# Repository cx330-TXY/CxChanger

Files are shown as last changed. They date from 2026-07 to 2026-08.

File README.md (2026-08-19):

# [CxChanger]

[CxChanger]是一种FDM3D打印多材料/多色解决方案。通过在打印打印过程中切换预热好的装载不同耗材的热端实现快速多材料打印。其目标是实现尽可能低成本且简单稳定的多材料打印，为了实现较高的适配性，热端切换只需要打印头XY轴运动就可实现，且切换结构与热端无关，可以通过修改热端固定件等实现其他热端的兼容。

English language readme is available [here](./EN-translation/README-EN.md)

打印头

QQ20260404-193802

---

## 核心特性
- **自动预热**：开启orcaslicer中的Ooze预防功能，会根据自己设定的预热时间提前在切换材料前插入预热命令，切换时释放旧热端并切换到待机温度然后抓取已经预热好的热端，若下一次切换的时间短于加热时间则保持温度不降温。
- **欠驱动切换机构**：采用欠驱动设计不需要额外增加主动元件，利用打印头自身的XY轴运动与停靠坞机械交互来实现热端切换和耗材丝夹紧松开。
- **磁吸麦克斯韦定位耦合机构**：热端模块锁定采用N52磁铁磁吸配合[麦克斯韦耦合](https://en.wikipedia.org/wiki/Kinematic_coupling)定位机构，打印头端有定位销组成的三个槽口，热端模块端有圆头销头部组成的球头。磁吸配合时实现对热端模块空间六自由度的限位，不存在过定位所以即使有加工装配误差以及磨损变形热端模块都能自适应消隙精确定位。
- **自动喷嘴偏移量校准**:采用校准器校准每个头XYZ轴相对T0的偏移量，可以使用如[小球微动接触式喷嘴偏移量校准](https://github.com/Noisyfox/FoxChanger/tree/main/NozzleProbe)或者[无接触涡流喷嘴偏移量校准](https://oshwhub.com/cxg01/project_lbabffjk)，接触式需要清理干净喷嘴才能获得正确喷嘴偏移量，无接触可以不清理喷嘴。不需要每次打印前都校准，通常在刚装配好或者出现撞头等情况需要校准。

## 硬件与软件需求

### 硬件
* **打印机** 原理上支持打印头具有XY移动能力的机型（如voron2.4、voron三叉戟、大鱼TT等），本开源只提供打印头和基础停靠坞设计需要根据自己机型固定装载停靠坞的铝型材和其他兼容修改。
* **主板** 由于采用有线加热，每个热端模块具有一个加热片和热敏，可利用主板空余接口来扩展少量热端模块，若需要扩展更多热端模块需要制作[扩展板]( https://oshwhub.com/rayzark/project_qxihkkhj)来增加主板的加热棒接口和热敏接口。

### 软件
* **固件** 整体热端切换通过klipper宏命令实现，若需使用喷嘴偏移量校准则需要下载[toolchange](https://github.com/viesturz/klipper-toolchanger)插件，配合自动校准宏来实现。
* **切片软件**：采用Orcaslicer，其他切片软件可自行探索。

## 组成概览

### 组成部分
- 打印头：有除了热端以外的其他部分
- 热端模块：包含热端，接有铁氟龙管和加热片和热敏的线
- 停靠坞：用于存放停靠的热端，可以堵住停靠热端的嘴防止漏料，以及有散热风扇给停靠的热端进行散热（无封箱的采用侧面离心风扇对所有热端进行散热、有封箱的采用每个停靠坞一个轴流风扇）。

### 零件
#### 打印版
- 1.5×5（直径*长）圆柱销：用于构成麦克斯韦耦合定位的槽（×6）
- 3×6（直径*长）圆头销：用于构成麦克斯韦耦合定位的球（一个热端3个）
- 5×20（直径*长）内螺纹圆头销：装配于停靠坞上用于撑开挤出机摆臂（一个停靠坞1个）
- 6×4（直径*厚）N52磁铁：用于吸附热端模块到打印头上和停靠坞上（一个热端3个，一个停靠坞1个，打印头3个）
- M3×6沉头螺丝
- M3×25螺丝
- M3×8螺丝
- M3×10螺丝
- M3×12螺丝
- M3×14螺丝
- M3×20螺丝
- M2.5×16螺丝
- M2×8螺丝
- M3×4×4热熔螺母
- HGX挤出机齿轮组
- 4020蜗轮风扇
- 2510轴流风扇
- 欧姆龙微动开关
- 10×2（宽×厚）自粘耐热硅胶条
#### CNC版
见bom表

## 安装与配置指南

### printer.cfg
   Printer.cfg主体可以沿用自己以前的，参考我的printer.cfg里的格式和下面的提示修改，也可以直接用我的然后改成自己主板的引脚。
   1. 引用 toolchange.cfg 和 calibration.cfg。
   2. 仿照extruder1格式定义增加的热端，加热棒热敏引脚按自己主板接线来，共用E0的挤出机，其他的为虚拟挤出机。
   3. probe采用固定微动，开始打印时热端全部停放于停靠坞中用耐高温硅胶垫堵嘴，加热到目标温度才拿出来解决初始漏料问题，不需要擦嘴，调平时未抓取热端此时微动为打印头最低点。还未支持其他调平方式，建议直接参考我的probe相关配置包括网床和调平的配置（主要是增加了调平前释放抓取的热端）。
   4. 添加停靠坞散热风扇配置，停靠坞散热风扇和喉管冷却风扇关联的挤出机里添加所有挤出机。
   5. 修改打印开始gcode，实现打印前自动给要使用的热端进行挤出划线。
   6. 修改打印结束gcode，添加UNTOOL命令保证打印完自动卸载热端，让下次打印时不用自己手动取下热端。增加关闭所有热端加热命令。
### toolchange.cfg
   1. 添加toolchange.cfg。添加成功后仪表盘界面会出现T0、T1、T2以及、UNTOOL命令，（没调坐标先别点、会直接撞）点击T0是抓去T0，抓取T0后再点击T1坐标会自动卸载T0然后抓取T1，点击UNTOOL是卸载当前热端。
   2. 固定停靠坞以及调整停靠坞坐标：手动把热端装到打印头上，把打印头拖动到X轴最右边，再往前拖动，然后把第一个停靠坞固定在能刚好让热端锁定螺丝穿过停靠坞大孔的位置（这个位置即为第一个停靠坞的坐标），然后取下热端，点击全部归位，再把热端装到打印头上，慢慢移动打印头到刚才找到的停靠坞位置让锁定螺丝穿过停靠坞大孔，记下此时的坐标将其填入toolchange里T0的停靠坞位置，一个停靠坞占30mm宽度，其他停靠坞坐标用等差数列得到，如有误差可自己微调每一个停靠坞的坐标。 
   

   3. 正确设置坐标后，注释正常速度，解除测试速度注释，用慢速进行切换测试，（方便看到没对齐直接点急停）。
   4. 测试速度切换正常后，注释测试速度，解除正常速度注释（可以根据自己机器情况自己测试出更为合适的速度）。
### calibration.cfg
   1. 下载[toolchange](https://github.com/viesturz/klipper-toolchanger)插件
   1. 添加calibration.cfg
   2. 归位xyz，调平完成后，固定好校准器，点击T0抓去第一个热端，移动至喷嘴尖端刚好位于校准器中心正上方距离1mm左右，记下这个时候的坐标，填入calibration.cfg里校准器坐标处，然后还需要在里面自己定义一个停靠坞范围外的安全位置，防止校准的时候撞到停靠坞里的其他热端。
   3. 坐标设置好后输入 CALIBRATE_TOOL TOOL=_ 可以校准指定热端（需要先校准T0），输入 CALIBRATE_ALL_TOOLS 可以校准全部（需要设定好有哪些热端），校准完成会自动存储偏移量。
### orcaslicer
   1. 修改打印机gcode里起始和耗材丝更换gcode、设置更多挤出机(根据自己热端数填写)、设置各挤出机切换耗材时回抽量（我设置的长度2mm）。
- 打印起始Gcode(根据自己的热端数修改)：
```Gcode
PRINT_START BED=[first_layer_bed_temperature] INITIAL_TOOL=[initial_tool] T0_TEMP={nozzle_temperature_initial_layer[0]} T0_USED={is_extruder_used[0]} T1_TEMP={nozzle_temperature_initial_layer[1]} T1_USED={is_extruder_used[1]} T2_TEMP={nozzle_temperature_initial_layer[2]} T2_USED={is_extruder_used[2]} T3_TEMP={nozzle_temperature_initial_layer[3]} T3_USED={is_extruder_used[3]} T4_TEMP={nozzle_temperature_initial_layer[4]} T4_USED={is_extruder_used[4]}
```
- 耗材更换Gcode：
```Gcode
M104 S{nozzle_temperature[next_extruder]} T{next_extruder}
T{next_extruder}
```
   2. 工艺栏里开启擦拭塔（如果料和参数调得好，且模型不涉及快速微小挤出，可以把模型拖到停靠坞旁边关掉擦料塔尝试无擦料塔打印）和Ooze自动预热（我设置的软化温度负180，预热时间35s，根据自己热端加热速度修改）。

## 注意事项
- 打印件采用abs打印，4层墙，60%填充。
- 挤出机弹簧需要拧得比常规挤出机更紧（因为为了压缩空间，力臂长度有限相同预紧力下挤出机夹紧力不如正常挤出机）。
- 为了减少热量传导效率，用到的TZ2.0热端需要去掉固定加热块的两个螺丝，仅靠侧面顶丝固定。
- 磁铁安装严格按图来（有的是压到底，有的是与某一面共面），装配正确应该是只有热端组件端的圆头销与背板端的圆柱销槽接触，磁铁之间有一点间隙，才能实现麦克斯韦耦合定位的自动消隙功能，可以自己晃动热端感觉有没有虚位，有虚位需要检查安装是否正确。当出现打印着精度变差的情况，需检查定位装配，容易出现磁铁没粘牢滑出与另一端的磁铁接触造成麦克斯韦耦合失效。
- 热端组件上用来挂在停靠坞孔里的挂钩螺丝用12.9级的杯头螺丝方便磁吸到停靠坞内，304材质螺丝无法正常吸附。

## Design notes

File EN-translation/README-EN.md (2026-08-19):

# [CxChanger]

> **Attribution / Credit**: Initial translation courtesy of [WheelsTheCat](https://github.com/WheelsTheCat/CxChanger). Translated content includes the README, Klipper configuration comments/messages, BOM spreadsheet, file names. For a translated STEP file refer to his repository.

[CxChanger] is a multi-material / multi-color solution for FDM 3D printing. It achieves fast multi-material printing by switching between preheated hotends loaded with different filaments during the print. The goal is multi-material printing that is as low-cost, simple, and stable as possible. For high adaptability, hotend switching only requires XY-axis motion of the print head, and the switching mechanism is independent of the hotend itself — other hotends can be made compatible by modifying the hotend mounting parts.
Print head

QQ20260404-193802

---

## Core Features
- **Automatic preheating**: With the Ooze Prevention feature enabled in OrcaSlicer, preheat commands are inserted before each material change according to your configured preheat time. During a switch, the old hotend is released and set to standby temperature, and the already-preheated hotend is picked up. If the time until the next switch is shorter than the heating time, the temperature is held without cooling down.
- **Underactuated switching mechanism**: The underactuated design requires no additional active components. It uses the print head's own XY-axis motion interacting mechanically with the dock to perform hotend switching and filament clamping/releasing.
- **Magnetic Maxwell kinematic coupling**: The hotend module is locked using N52 magnets combined with a [Maxwell coupling](https://en.wikipedia.org/wiki/Kinematic_coupling) locating mechanism. The print head side has three grooves formed by locating pins, and the hotend module side has ball ends formed by round-head pin tips. When magnetically coupled, all six spatial degrees of freedom of the hotend module are constrained. Because there is no over-constraint, the hotend module can self-adaptively compensate for backlash and locate precisely even with machining/assembly errors, wear, and deformation.
- **Automatic nozzle offset calibration**: A calibrator measures each head's XYZ offset relative to T0. You can use, for example, [ball-probe contact nozzle offset calibration](https://github.com/Noisyfox/FoxChanger/tree/main/NozzleProbe) or [non-contact eddy-current nozzle offset calibration](https://oshwhub.com/cxg01/project_lbabffjk). Contact calibration requires a clean nozzle for correct offsets; non-contact does not. Calibration is not needed before every print — it is typically only required after initial assembly or after events such as a head crash.

## Hardware and Software Requirements

### Hardware
* **Printer**: In principle, any machine whose print head can move in XY is supported (e.g., Voron 2.4, Voron Trident, BIQU/BigTreeTech, etc.). This open-source project only provides the print head and basic dock designs; you will need to adapt the aluminum extrusion mounting for the dock and make other compatibility modifications for your machine.
* **Main board**: Since wired heating is used, each hotend module has its own heater and thermistor. Spare ports on the main board can be used to add a small number of hotend modules. To add more, build an [expansion board](https://oshwhub.com/rayzark/project_qxihkkhj) to increase the number of heater and thermistor ports.

### Software
* **Firmware**: Hotend switching is implemented entirely through Klipper macros. If you want to use nozzle offset calibration, install the [toolchanger](https://github.com/viesturz/klipper-toolchanger) plugin and use it together with the automatic calibration macros.
* **Slicer**: OrcaSlicer is used; other slicers can be explored on your own.

## System Overview

### Components
- Print head: everything except the hotend
- Hotend module: contains the hotend, with PTFE tube and heater/thermistor wiring attached
- Dock: stores parked hotends. It plugs the nozzle of a parked hotend to prevent oozing, and has cooling fans for the parked hotends (open-frame machines use a side centrifugal fan cooling all hotends; enclosed machines use one axial fan per dock).

### Parts
#### Printed version
- 1.5×5 (diameter×length) cylindrical pins: form the grooves of the Maxwell coupling (×6)
- 3×6 (diameter×length) round-head pins: form the balls of the Maxwell coupling (3 per hotend)
- 5×20 (diameter×length) internally threaded round-head pin: mounted on the dock to spread open the extruder swing arm (1 per dock)
- 6×4 (diameter×thickness) N52 magnets: attach the hotend module to the print head and dock (3 per hotend, 1 per dock, 3 on the print head)
- M3×6 countersunk screws
- M3×25 screws
- M3×8 screws
- M3×10 screws
- M3×12 screws
- M3×14 screws
- M3×20 screws
- M2.5×16 screws
- M2×8 screws
- M3×4×4 heat-set inserts
- HGX extruder gear set
- 4020 blower fan
- 2510 axial fan
- Omron micro switch
- 10×2 (width×thickness) self-adhesive heat-resistant silicone strip
#### CNC version
See the BOM sheet

## Installation and Configuration Guide

### printer.cfg
   You can keep using your existing printer.cfg as the base. Modify it following the format in my printer.cfg and the notes below, or use mine directly and change the pins to match your board.
   1. Include toolchange.cfg and calibration.cfg.
   2. Define the additional hotends following the extruder1 format. Wire the heater and thermistor pins according to your board. They share E0's extruder motor; the others are virtual extruders.
   3. The probe uses a fixed micro switch. At print start, all hotends are parked in the dock with their nozzles plugged by the high-temperature silicone pads, and are only picked up once heated to the target temperature — this solves the initial oozing problem, and no nozzle wiping is needed. During leveling no hotend is attached, so the micro switch is the lowest point of the print head. Other leveling methods are not yet supported; it is recommended to use my probe-related configuration directly, including the bed mesh and leveling configuration (mainly the addition of releasing the grabbed hotend before leveling).
   4. Add the dock cooling fan configuration, and add all extruders to the extruder association of the dock cooling fan and the heatbreak cooling fan.
   5. Modify the print start G-code to automatically prime (extrude a line with) each hotend that will be used before printing.
   6. Modify the print end G-code to add the UNTOOL command so the hotend is automatically unloaded after printing, avoiding manual removal before the next print. Add commands to turn off all hotend heaters.
### toolchange.cfg
   1. Add toolchange.cfg. Once added successfully, T0, T1, T2 and UNTOOL commands will appear in the dashboard. (Do not click them before setting the coordinates — it will crash the head.) Clicking T0 picks up T0; after picking up T0, clicking T1 automatically unloads T0 and picks up T1; clicking UNTOOL unloads the current hotend.
   2. Mount the dock and adjust the dock coordinates: manually attach a hotend to the print head, move the print head to the far right of the X axis, then move it forward. Fix the first dock in the position where the hotend locking screw just passes through the dock's large hole (this position is the coordinate of the first dock). Then remove the hotend, home all axes, re-attach the hotend to the print head, and slowly move the print head to the dock position you just found so the locking screw passes through the dock's large hole. Note the coordinates and enter them as T0's dock position in toolchange.cfg. Each dock occupies 30 mm of width, so the other dock coordinates form an arithmetic sequence; fine-tune each dock's coordinates if there is any error.
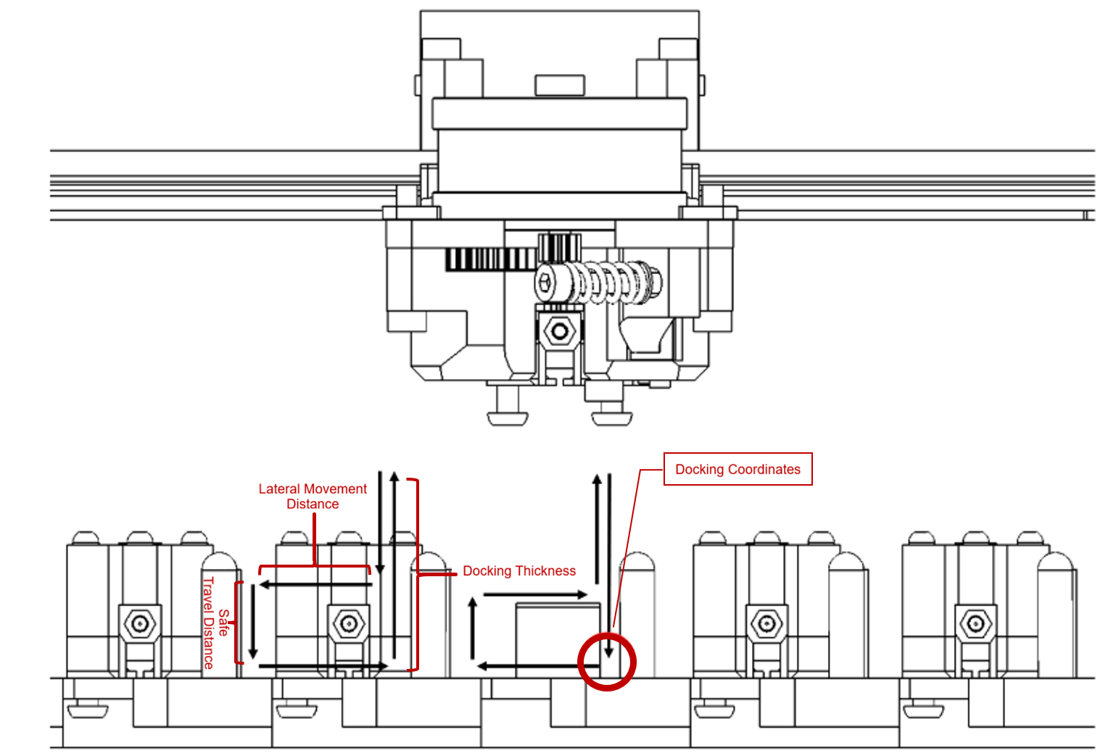
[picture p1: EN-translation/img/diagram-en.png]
Dock coordinate diagram
   

   3. After setting the coordinates correctly, comment out the normal speed and uncomment the test speed, then run switching tests at slow speed (so you can hit emergency stop immediately if anything is misaligned).
   4. Once switching works at test speed, comment out the test speed and uncomment the normal speed (you can test and tune more suitable speeds for your own machine).
### calibration.cfg
   1. Download the [toolchanger](https://github.com/viesturz/klipper-toolchanger) plugin
   1. Add calibration.cfg
   2. Home XYZ. After leveling completes, mount the calibrator, click T0 to pick up the first hotend, and move it until the nozzle tip is directly above the center of the calibrator at a distance of about 1 mm. Note the coordinates and enter them as the calibrator coordinates in calibration.cfg. You also need to define a safe position outside the dock area in the file, to avoid hitting the other hotends in the dock during calibration.
   3. Once the coordinates are set, run CALIBRATE_TOOL TOOL=_ to calibrate a specific hotend (T0 must be calibrated first), or CALIBRATE_ALL_TOOLS to calibrate all of them (set which hotends exist first). Offsets are stored automatically when calibration completes.
### orcaslicer
   1. In the printer G-code, modify the start G-code and the filament change G-code; configure additional extruders (according to your number of hotends); set the retraction amount for each extruder when switching filament (I use 2 mm).
- Print start G-code (modify according to your number of hotends):
```Gcode
PRINT_START BED=[first_layer_bed_temperature] INITIAL_TOOL=[initial_tool] T0_TEMP={nozzle_temperature_initial_layer[0]} T0_USED={is_extruder_used[0]} T1_TEMP={nozzle_temperature_initial_layer[1]} T1_USED={is_extruder_used[1]} T2_TEMP={nozzle_temperature_initial_layer[2]} T2_USED={is_extruder_used[2]} T3_TEMP={nozzle_temperature_initial_layer[3]} T3_USED={is_extruder_used[3]} T4_TEMP={nozzle_temperature_initial_layer[4]} T4_USED={is_extruder_used[4]}
```
- Filament change G-code:
```Gcode
M104 S{nozzle_temperature[next_extruder]} T{next_extruder}
T{next_extruder}
```
   2. In the Process settings, enable the wipe tower (if your filament and settings are well tuned and the model does not involve fast tiny extrusions, you can move the model next to the dock, disable the wipe tower, and try printing without one) and enable Ooze automatic preheating (I use a softening temperature offset of -180 and a preheat time of 35 s; adjust for your hotend's heating speed).

## Notes
- Printed parts should be printed in ABS with 4 walls and 60% infill.
- The extruder spring must be tightened more than on a regular extruder (to save space the lever arm is limited, so at the same preload the clamping force is lower than a normal extruder).
- To reduce heat conduction, the TZ2.0 hotend used here needs the two screws that fix the heater block removed, holding it only with the side set screw.
- Install the magnets exactly as shown in the drawings (some are pressed fully in, some are flush with a face). When assembled correctly, only the round-head pins on the hotend module side touch the cylindrical-pin grooves on the back plate side, with a small gap between the magnets — this enables the automatic backlash compensation of the Maxwell coupling. Wiggle the hotend to check for play; if there is play, check the installation. If print accuracy degrades during printing, check the locating assembly — a common issue is a magnet coming loose, sliding out, and contacting the magnet on the other side, which defeats the Maxwell coupling.
- The hook screws on the hotend module that hang in the dock holes should be grade 12.9 cap-head screws so they are attracted by the magnets in the dock; 304 stainless steel screws will not be attracted properly.

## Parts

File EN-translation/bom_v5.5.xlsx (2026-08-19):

Item No. | Part No. | Quantity | Price | Link
HGX extruder gear kit | 17/44 dual gear | 1 | 35.5 | https://item.taobao.com/item.htm?id=682175013983
 | 36-tooth extruder gear | 2
 | Cylindrical pin dia 3 x len 16 | 2
 | Bearing OD 6 x ID 3 x thk 2.5 | 4
 | Compression spring | 1
 | Cylindrical pin dia 3 x len 24 | 1
Printed part | Hotend mount | 1
 | Dock | Quantity as needed
 | Air duct (revised) | 1
JLCCNC panelized CNC | Top magnet mounting plate | 1 | 10 | Use the twice-monthly free prototyping offer and tap the threads yourself. If you cannot tap them yourself, JLC will tap one for 1 RMB (5 M3 screw holes in total)
 | Spring support plate | 1
 | Swing lever inner (CNC) | 1
 | Swing lever inner (CNC) | 1
 | Simplified cover plate | 1
 | Print head back plate | 1
 | Simplified cover plate | 1
 | PTFE tube ID 2 x OD 4 | Hotend mount, printed part, inner-wall infill
 | Cylindrical pin dia 1.5 x len 5 | Forms the grooves of the Maxwell coupling locating mechanism (x6) |  | https://detail.tmall.com/item.htm?id=1013104858939
 | Internally threaded round-head pin M3, OD 5 x len 18 | Mounted on the dock to spread open the extruder swing arm (1 per dock) |  | https://detail.tmall.com/item.htm?id=864132087543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
 | Round-head pin dia 3 x len 4 | Forms the balls of the Maxwell coupling locating mechanism (3 per hotend) |  | https://detail.tmall.com/item.htm?id=868817943817
 | TZ2.0 | Quantity as needed
 | N52 magnet dia 6 x thk 4 | Used to attach the hotend module to the print head and dock (3 per hotend, 1 per dock, 3 on the print head) |  | https://item.taobao.com/item.htm?id=968742198263
 | 2510 fan | 1
 | 36 pancake stepper motor | 1
 | Micro switch | 1
 | M4 hex standoff 10 | 2 |  | https://item.taobao.com/item.htm?abbucket=19&id=790190576194&ns=1&skuId=5961506598999&xxc=taobaoSearch
 | M4 hex standoff 14 | 1
 | M4 bolt with hole | 1
 | 4020 centrifugal fan | 1
 | Cap head M3*8 | 2
 | M4 nut | 1
 | Round head M3*22 | 7
 | Cap head M3*15 | 3
 | Cap head M2.5*14 | 2
 | M3 nut | 5
 | Cap head M3*6 | 1
 | Cap head M3*10 | 3
 | Cap head M2*8 | 2
 | The dock has no unified design so its screws are not listed here; judge the screw types yourself

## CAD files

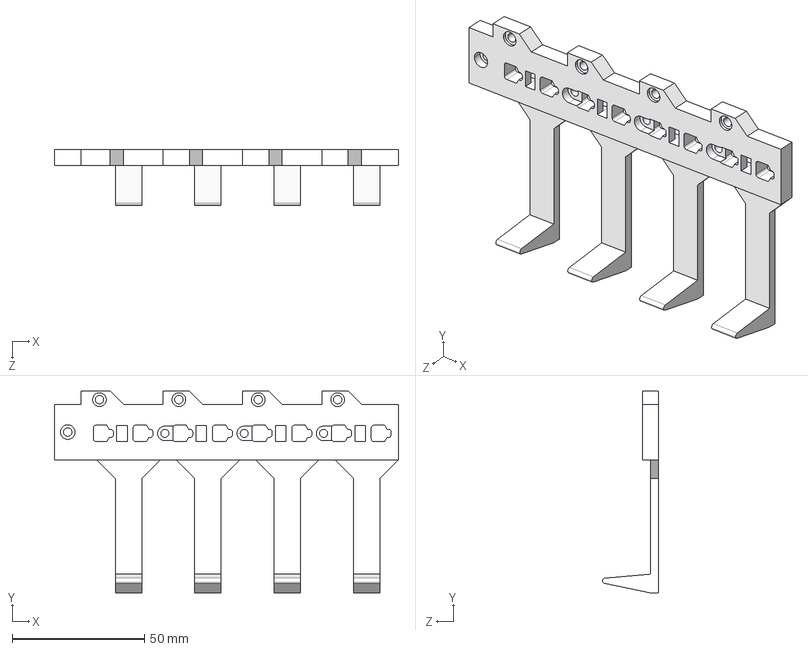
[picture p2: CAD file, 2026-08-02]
CAD/热端停靠坞6.11改.STEP
130.0 x 76.3 x 21.2 mm

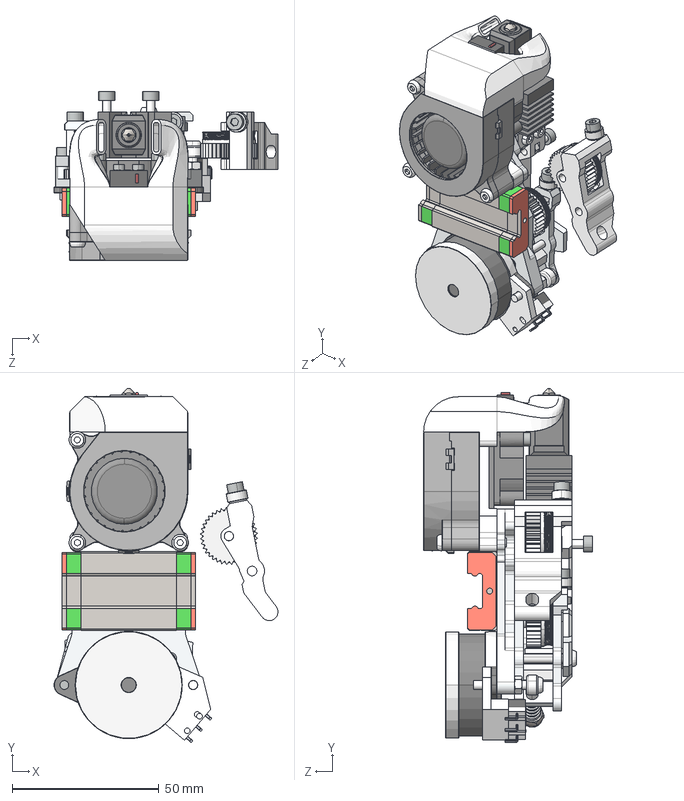
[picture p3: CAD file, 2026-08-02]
CAD/打印头6.11（新增换头失败和断料检测）.STEP
76.3 x 120.6 x 57.5 mm
17 44双联齿轮
36齿挤出齿轮 x 3
直径3长16圆柱销 x 2
圆柱销外径1.5长5 x 6
轴承外径6内径3厚2.5 x 3
N52磁铁 6 4 x 6
36圆饼步进电机
2510风扇
热端固定件
散热翅片_拓竹
喷嘴+喉管_拓竹
P1P陶瓷加热片
硅胶套
圆柱头螺栓_M3*10 x 2
耗材丝
圆头销外径3长4 x 3
M3螺母 x 7
半圆头螺栓_M3*22 x 6
M4带孔螺栓
压簧
百瑞特防滑螺母_M4
顶部磁铁固定板
弹簧撑板
圆柱头螺栓_M3*15 x 2
圆柱头螺栓_M2.5*14 x 2
直径3长24圆柱销
M4六角隔离柱10 x 2
M4六角隔离柱14
简化盖板_简化盖板左
简化盖板_简化盖板右
4020离心风扇_По умолчанию
打印头背板cnc（三叉戟）
MGN12H
摆杆外带轴承（CNC）
轴承_3x7x3 x 2
摆杆外带轴承（CNC）_摆杆内
圆柱头螺栓_M3*8 x 2
垫圈_3.2*6*0.5 x 2
沉头螺栓_M3*16
带轴承摆臂打印一体式
杂交风道
micro switch_Varsayılan x 2
圆柱头螺栓_M2*10 x 2
微动固定
打印头线固定
半圆头螺栓_M3*25

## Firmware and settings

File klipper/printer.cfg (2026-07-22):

[respond]          # 必须：开启 M118 信息输出功能
[pause_resume]     # 必须：开启暂停/恢复功能
[display_status]   # 建议：用于在界面显示状态
[virtual_sdcard]
path: /usr/share/printer_data/gcodes

[gcode_macro PAUSE]
rename_existing: BASE_PAUSE
gcode:
    # ----- 参数设置 -----
    {% set z_hop = 5.0 %}           ; 暂停时抬升的高度 (mm)
    {% set x_park = 10.0 %}         ; 停车位置 X 坐标
    {% set y_park = 10.0 %}         ; 停车位置 Y 坐标
    {% set retract_len = 0 %}     ; 暂停时的回抽长度 (mm)
    
    # 1. 保存当前 G-code 状态（包含坐标、挤出模式、偏置等）
    SAVE_GCODE_STATE NAME=PAUSE_state
    
    # 2. 执行基础暂停指令
    BASE_PAUSE
    
    # 3. 安全回抽并抬升
    {% if printer.extruder.can_extrude %}
        M83                          ; 相对挤出模式
        G1 E-{retract_len} F2100     ; 稍微回抽防止滴漏
    {% endif %}
    
    # 4. 计算 Z 轴抬升高度（防止撞到顶端限制）
    {% set max_z = printer.toolhead.axis_maximum.z|float %}
    {% set cur_z = printer.toolhead.position.z|float %}
    {% if cur_z < (max_z - z_hop) %}
        {% set z_safe = z_hop %}
    {% else %}
        {% set z_safe = max_z - cur_z %}
    {% endif %}

    G91                              ; 相对坐标模式
    G1 Z{z_safe} F900                ; 抬升 Z 轴，离开模型表面
    
    # 5. 移动到侧边停靠点
    G90                              ; 绝对坐标模式
    G1 X{x_park} Y{y_park} F18000    ; 快速移动到路边
    
    M118 [系统] 已安全停车，等待人工处理...

[gcode_macro RESUME]
rename_existing: BASE_RESUME
gcode:
    {% set retract_len = 0 %}      ; 必须与 PAUSE 里的回抽量一致
    
    # 1. 检查挤出机温度是否达标，防止冷挤出
    {% if printer.extruder.can_extrude %}
        M83
        G1 E{retract_len} F2100      ; 补回刚才回抽的料
    {% endif %}
    
    # 2. 恢复保存的状态（会自动回到暂停前的坐标，并恢复速度限制）
    # MOVE=1 表示让机器自动移动回暂停前的 X Y Z 位置
    RESTORE_GCODE_STATE NAME=PAUSE_state MOVE=1 MOVE_SPEED=150
    
    M118 [系统] 准备恢复打印...
    BASE_RESUME
    
[gcode_macro CANCEL_PRINT]
description: Cancel the actual running print
rename_existing: CANCEL_PRINT_BASE
gcode:
  TURN_OFF_HEATERS
  CANCEL_PRINT_BASE
  G91
  G1 Z10 F600 ; 抬高喷嘴10mm避免烫坏模型
  UNTOOL
  M106 S0
[force_move]
enable_force_move: True
#####################################################################
#                               文件调用                               #
#####################################################################
[include toolchange.cfg]
[include calibration.cfg]
#[include idm.cfg]
#####################################################################
#                               主板配置                               #
#####################################################################
[mcu]
serial:/dev/serial/by-id/usb-Klipper_stm32f407xx_36003D001650334636343620-if00



#[mcu host]
#serial: /tmp/klipper_host_mcu

#####################################################################
#                            副板扩展配置                             #
#####################################################################
#[mcu expander]
# 这里填入你在第一步获取到的新主板ID
#serial: /dev/serial/by-id/usb-Klipper_stm32f072xb_3F0035000357465036383420-if00 
#####################################################################
#                            机型和加速度                            #
#####################################################################
[printer]                       # 打印机设置
kinematics: corexy              # 运动学结构分为：笛卡尔和corexy等等。笛卡尔：cartesian
max_velocity: 400               # 打印机最大速度   
max_accel: 20000                 # 最大加速度 
max_z_velocity: 30              # z轴最大速度
max_z_accel: 300                # z轴最大加速度
square_corner_velocity: 5.0     # 方形拐角速度，小一点可以有效避免平台重带来的惯性
#####################################################################
#                             温度监控                               #
#####################################################################
[temperature_sensor MCU]    
sensor_type: temperature_mcu   

[temperature_sensor FLY-Pi]
sensor_type: temperature_host
#####################################################################
#             X/Y步进电机设置 (X/Y Stepper Settings)                 # 
#####################################################################
#   B Motor ---- Motor A 
#   |                  |
#   |------挤出机-------|
#   |                  |
#   |                  |
#          正前方   
#####################################################################
#                          X 轴步进电机   (B 电机)                    #
#####################################################################
## X电机口
[stepper_x]
step_pin: PB9                       # X轴电机脉冲引脚设置
dir_pin: PE0                        # X轴电机运行引脚设置,方向按实际判断,加感叹号会让运行方向反转
enable_pin: !PE1                    # X轴电机使能引脚设置,使能引脚需要加感叹号,否则电机不工作
rotation_distance: 40               # 主动带轮周长mm(2GT-20T带轮40,2GT-16T带轮32)
microsteps: 32                      # 电机细分设置,细分越高,质量越高,但主控负荷越大
full_steps_per_rotation: 200        # 电机单圈所需脉冲数(1.8度电机:200,0.9度电机:400)
endstop_pin: PC3                   # 限位开关PIN脚,建议常闭然后添加!反转状态,位置在io-3
###接常闭后是触发状态,加感叹号可以反转这个状态,万一断线时可以避免撞机
position_min: -5                     # 软限位最小行程
position_endstop: 240               # 软限位最大行程 (250mm-300mm-350mm)
position_max: 240                   # 机械限位最大行程 (250mm-300mm-350mm)
homing_speed: 80                    # 复位速度,最大为100.归位速度建议别太快
homing_retract_dist: 0              # 第一次触发复位开关之后的后退距离
#--------------------------------------------------------------------
##  请确保驱动型号配置正确 (2208 or 2209)
[tmc2209 stepper_x]                 # X 驱动配置 -TMC2209
uart_pin: PG13                      # 通讯端口Pin脚定义
interpolate: False                  # 是否开启256微步插值(开启是True,关闭是False)
run_current: 1.1                    # 运行电流
sense_resistor: 0.110               # 驱动采样电阻不要改
#####################################################################
#                       y 轴步进电机   (A 电机)                       #
#####################################################################
## Y电机口
[stepper_y]
step_pin: PB8                       # Y轴电机脉冲引脚设置
dir_pin: PG11                       # Y轴电机运行引脚设置,方向按实际判断,加感叹号会让运行方向反转
enable_pin: !PG12                   # Y轴电机使能引脚设置,使能引脚需要加感叹号,否则电机不工作
rotation_distance: 40               # 主动带轮周长mm(2GT-20T带轮40,2GT-16T带轮32)
microsteps: 32                      # 电机细分设置,细分越高,质量越高,但主控负荷越大
full_steps_per_rotation: 200        # 电机单圈所需脉冲数(1.8度电机:200,0.9度电机:400)
endstop_pin: PC2                   # 限位开关PIN脚,建议常闭然后添加!反转状态,位置在io-0
###接常闭后是触发状态,加感叹号可以反转这个状态,万一断线时可以避免撞机
position_min: -33                     # 软限位最小行程
position_endstop: 230               # 软限位最大行程 (250mm-300mm-350mm)
position_max: 230                   # 机械限位最大行程 (250mm-300mm-350mm)
homing_speed: 80                    # 复位速度,最大为100        归位速度建议别太快
homing_retract_dist: 0              # 第一次触发复位开关之后的后退距离
#--------------------------------------------------------------------
##  请确保驱动型号配置正确 (2208 or 2209)
[tmc2209 stepper_y]                 # Y驱动配置 -TMC2209
uart_pin: PG10                      # 通讯端口Pin脚定义
interpolate: False                  # 是否开启256微步插值(开启是True,关闭是False)
run_current: 1.1                    # 运行电流
sense_resistor: 0.110               # 驱动采样电阻不要改
#--------------------------------------------------------------------
#[tmc5160 stepper_y]                 # 挤出机驱动配置- TMC5160
#cs_pin: PG10                        # SPI 片选Pin脚定义
#spi_bus: spi2                      # SPI 通讯总线定义
#run_current: 1.0                    # 电机运行电流值
#interpolate: False                  # 是否开启256微步插值(开启是True,关闭是False)
#sense_resistor: 0.075              # 驱动采样电阻不要改(如果使用5160 Pro,请将数值修改为0.033)

#####################################################################
#                     Z轴步进电机 (Z Stepper Settings)              #
#####################################################################
#   |----- Z1 -----|
#   |              |
#   |              |
#   |              |
#   Z0----显示屏----Z2

#####################################################################
#                           Z轴步进电机                              #
#####################################################################
##    Z步进电机 - 左前方 z接口
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

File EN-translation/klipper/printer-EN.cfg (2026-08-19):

[respond]          # Required: enables M118 message output
[pause_resume]     # Required: enables pause/resume functionality
[display_status]   # Recommended: shows status in the UI
[virtual_sdcard]
path: /usr/share/printer_data/gcodes

[gcode_macro PAUSE]
rename_existing: BASE_PAUSE
gcode:
    # ----- Parameter settings -----
    {% set z_hop = 5.0 %}           ; Lift height on pause (mm)
    {% set x_park = 10.0 %}         ; Park position X coordinate
    {% set y_park = 10.0 %}         ; Park position Y coordinate
    {% set retract_len = 0 %}     ; Retraction length on pause (mm)
    
    # 1. Save the current G-code state (coordinates, extrusion mode, offsets, etc.)
    SAVE_GCODE_STATE NAME=PAUSE_state
    
    # 2. Execute the base pause command
    BASE_PAUSE
    
    # 3. Safe retraction and lift
    {% if printer.extruder.can_extrude %}
        M83                          ; Relative extrusion mode
        G1 E-{retract_len} F2100     ; Retract slightly to prevent dripping
    {% endif %}
    
    # 4. Calculate the Z lift height (avoid hitting the top limit)
    {% set max_z = printer.toolhead.axis_maximum.z|float %}
    {% set cur_z = printer.toolhead.position.z|float %}
    {% if cur_z < (max_z - z_hop) %}
        {% set z_safe = z_hop %}
    {% else %}
        {% set z_safe = max_z - cur_z %}
    {% endif %}

    G91                              ; Relative coordinate mode
    G1 Z{z_safe} F900                ; Lift Z away from the model surface
    
    # 5. Move to the side park position
    G90                              ; Absolute coordinate mode
    G1 X{x_park} Y{y_park} F18000    ; Move quickly to the side
    
    M118 [System] Parked safely; waiting for manual intervention...

[gcode_macro RESUME]
rename_existing: BASE_RESUME
gcode:
    {% set retract_len = 0 %}      ; Must match the retraction amount in PAUSE
    
    # 1. Check that the extruder temperature is sufficient to prevent cold extrusion
    {% if printer.extruder.can_extrude %}
        M83
        G1 E{retract_len} F2100      ; Re-prime the filament retracted earlier
    {% endif %}
    
    # 2. Restore the saved state (automatically returns to the pre-pause position and restores speed limits)
    # MOVE=1 makes the machine automatically move back to the pre-pause X Y Z position
    RESTORE_GCODE_STATE NAME=PAUSE_state MOVE=1 MOVE_SPEED=150
    
    M118 [System] Preparing to resume printing...
    BASE_RESUME
    
[gcode_macro CANCEL_PRINT]
description: Cancel the actual running print
rename_existing: CANCEL_PRINT_BASE
gcode:
  TURN_OFF_HEATERS
  CANCEL_PRINT_BASE
  G91
  G1 Z10 F600 ; Lift the nozzle 10mm to avoid scorching the model
  UNTOOL
  M106 S0
[force_move]
enable_force_move: True
#####################################################################
#                            File includes                          #
#####################################################################
[include toolchange.cfg]
[include calibration.cfg]
#[include idm.cfg]
#####################################################################
#                        Main board configuration                   #
#####################################################################
[mcu]
serial:/dev/serial/by-id/usb-Klipper_stm32f407xx_36003D001650334636343620-if00



#[mcu host]
#serial: /tmp/klipper_host_mcu

#####################################################################
#                    Expansion board configuration                  #
#####################################################################
#[mcu expander]
# Enter the new board ID you obtained in step one here
#serial: /dev/serial/by-id/usb-Klipper_stm32f072xb_3F0035000357465036383420-if00 
#####################################################################
#                     Machine type and acceleration                 #
#####################################################################
[printer]                       # Printer settings
kinematics: corexy              # Kinematics types include Cartesian, corexy, etc. Cartesian: cartesian
max_velocity: 400               # Printer maximum speed   
max_accel: 20000                 # Maximum acceleration 
max_z_velocity: 30              # Z-axis maximum speed
max_z_accel: 300                # Z-axis maximum acceleration
square_corner_velocity: 5.0     # Square corner velocity; a smaller value helps counter inertia from a heavy bed
#####################################################################
#                        Temperature monitoring                     #
#####################################################################
[temperature_sensor MCU]    
sensor_type: temperature_mcu   

[temperature_sensor FLY-Pi]
sensor_type: temperature_host
#####################################################################
#             X/Y Stepper Settings                                  # 
#####################################################################
#   B Motor ---- Motor A 
#   |                  |
#   |-----extruder-----|
#   |                  |
#   |                  |
#          front   
#####################################################################
#                     X-axis stepper motor (B motor)                #
#####################################################################
## X motor port
[stepper_x]
step_pin: PB9                       # X-axis motor step pin
dir_pin: PE0                        # X-axis motor direction pin; determine direction by testing; adding "!" reverses the direction
enable_pin: !PE1                    # X-axis motor enable pin; the enable pin needs "!", otherwise the motor won't work
rotation_distance: 40               # Drive pulley circumference in mm (2GT-20T pulley: 40, 2GT-16T pulley: 32)
microsteps: 32                      # Motor microstep setting; higher microstepping gives higher quality but more MCU load
full_steps_per_rotation: 200        # Pulses per motor revolution (1.8-degree motor: 200, 0.9-degree motor: 400)
endstop_pin: PC3                   # Limit switch pin; recommended normally closed then add "!" to invert; located at io-3
###When wired normally closed it reads as triggered; adding "!" inverts this so a broken wire won't crash the machine
position_min: -5                     # Soft limit minimum travel
position_endstop: 240               # Soft limit maximum travel (250mm-300mm-350mm)
position_max: 240                   # Mechanical limit maximum travel (250mm-300mm-350mm)
homing_speed: 80                    # Homing speed, maximum 100. It's best not to home too fast
homing_retract_dist: 0              # Back-off distance after first triggering the homing switch
#--------------------------------------------------------------------
##  Make sure the driver model is configured correctly (2208 or 2209)
[tmc2209 stepper_x]                 # X driver configuration - TMC2209
uart_pin: PG13                      # Communication port pin definition
interpolate: False                  # Whether to enable 256-microstep interpolation (True to enable, False to disable)
run_current: 1.1                    # Run current
sense_resistor: 0.110               # Driver sense resistor; do not change
#####################################################################
#                     Y-axis stepper motor (A motor)                #
#####################################################################
## Y motor port
[stepper_y]
step_pin: PB8                       # Y-axis motor step pin
dir_pin: PG11                       # Y-axis motor direction pin; determine direction by testing; adding "!" reverses the direction
enable_pin: !PG12                   # Y-axis motor enable pin; the enable pin needs "!", otherwise the motor won't work
rotation_distance: 40               # Drive pulley circumference in mm (2GT-20T pulley: 40, 2GT-16T pulley: 32)
microsteps: 32                      # Motor microstep setting; higher microstepping gives higher quality but more MCU load
full_steps_per_rotation: 200        # Pulses per motor revolution (1.8-degree motor: 200, 0.9-degree motor: 400)
endstop_pin: PC2                   # Limit switch pin; recommended normally closed then add "!" to invert; located at io-0
###When wired normally closed it reads as triggered; adding "!" inverts this so a broken wire won't crash the machine
position_min: -33                     # Soft limit minimum travel
position_endstop: 230               # Soft limit maximum travel (250mm-300mm-350mm)
position_max: 230                   # Mechanical limit maximum travel (250mm-300mm-350mm)
homing_speed: 80                    # Homing speed, maximum 100        It's best not to home too fast
homing_retract_dist: 0              # Back-off distance after first triggering the homing switch
#--------------------------------------------------------------------
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

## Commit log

2026-07-17 Revise Gcode for print start and material change
    Updated the starting Gcode for printing to use new parameters and improved clarity on material change Gcode.
2026-08-12 Reformat readmes and add extra translated files
    [bom_v5.5.xlsx, calibration-EN.cfg, printer-EN.cfg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]
